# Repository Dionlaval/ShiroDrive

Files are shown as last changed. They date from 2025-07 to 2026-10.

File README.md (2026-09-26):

# ShiroDrive

ShiroDrive is an independent motion-control project focused on modular motor-drive hardware and experimental robotic systems.

The current hardware direction includes both stepper control and compact, networked FOC servo modules.

This is an evolving engineering project.

---

## Core Direction

ShiroDrive currently explores:

- Custom stepper motor driver design
- Dynamic microstepping techniques
- Smooth motion across wide velocity ranges
- Resonance mitigation and control refinement
- CoreXY motion architectures

The stepper platform uses ESP32, while ShiroFOC is based on the STSPIN32G4 with its embedded STM32G431 motor-control MCU.

ESP32 provides:

- Real-time capable control
- Flexible peripheral configuration
- Wireless debugging and telemetry
- Rapid prototyping flexibility

STSPIN32G4 provides:

- Integrated STM32G4 real-time motor-control MCU
- Three external-MOSFET gate drivers
- Integrated current-sense op-amps and hardware protection comparators
- CAN-based modular communication
- Compact single-axis FOC architecture

---

## Building Block

### ShiroDrive Step

A custom stepper motor control platform.

Focus areas:

- Dynamic microstepping
- High-speed stability
- Clean current control
- Modular PCB design
- Firmware-driven motion refinement

This board forms the foundation of all current machines.

### ShiroFOC

A single-axis, 48 V-class FOC servo module for robotics.

Planned features include:

- STSPIN32G4 controller and external three-phase MOSFET bridge
- Three-shunt phase-current sensing
- CAN communication to a coordinating motherboard
- Integrated magnetic encoder and 6-axis IMU
- External Hall and encoder inputs
- SWD programming and debug

See [ShiroFOC design constraints](ShiroFOC/docs/DESIGN_CONSTRAINTS.md) for the preliminary Rev A targets.

---

## Experimental Machine

### Manga Draw

A CoreXY-based pen plotting platform.

Purpose:

- Investigate high-speed planar motion
- Develop scalable XY architecture
- Render anime-style posters and manga panels with precision
- Serve as a validation platform for ShiroDrive Step

The architecture is designed to scale beyond desktop format.

---

## Development Status

### Currently Working On

- ShiroDrive Step PCB iteration
- Motion firmware development (ESP32)
- CoreXY Manga Draw platform integration

### Next Steps

- Refinement of dynamic microstepping
- Mechanical rigidity improvements
- Higher current driver revisions
- Closed-loop motion experimentation

---

ShiroDrive documents the process of building motion systems from first principles — hardware, firmware, and mechanical integration.

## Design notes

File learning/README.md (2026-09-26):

# ShiroFOC weekend learning lab

**Start with [the interactive lab](index.html)**. Open `index.html` in a browser; it works offline, with no installation or server. Work through one chapter at a time alongside [the notebook](docs/NOTEBOOK.md).

This package turns the [learning plan](docs/PCB_DESIGN_LEARNING_PLAN.md) into worked models, experiments and board-specific explanations. It is designed for a mechanical engineer with a robotics and control background.

## Suggested route

| Session | Read and do | Approximate time |
|---|---|---|
| Saturday morning | Notebook §§1–3; lab “Switching”; exercises 1–3 | 1.5–2 h |
| Saturday afternoon | Notebook §§4–7; “Capacitors” and “Supply & energy”; exercises 4–8 | 2–3 h |
| Sunday morning | Notebook §§8–10; “Placement” and “Sensing”; exercises 9–12 | 2–3 h |
| Sunday afternoon | Notebook §11; decision record; write your own capacitor decision | 1–2 h |

Take breaks between models. You do not need to absorb all the equations before experimenting.

## Deliverables

- [Interactive lab](index.html): live switching, capacitor, RLC, gate-drive and sensing models. Hover/touch plots to inspect values; controls show units.
- [Guided notebook](docs/NOTEBOOK.md): physical explanations, worked numbers and predictions.
- [Board inputs](docs/BOARD_INPUTS.md): actual component values, operating targets and assumed parameters.
- [Model guide](docs/MODEL_GUIDE.md): derivations, topology definitions, implementation details and limits.
- [Exercises with answers](docs/EXERCISES.md): prediction-first experiments and numerical checks.
- [Decision record](docs/DECISION_RECORD.md): consequences for this board and what remains undecided.
- [Sources](docs/SOURCES.md): project evidence and primary engineering references.
- [Figures](figures/): standalone PNG and SVG plots, power-path diagram and actual placement overview.
- [Comparison CSV](data/comparison.csv), [JSON](data/comparison.json) and waveform CSVs: reusable numeric results.
- [Python model](models/build_models.py) and [browser model](models/lab_models.js): editable, documented implementations.
- [Runnable Jupyter notebook](ShiroFOC_learning.ipynb): optional computational companion; the browser lab requires no Python.
- [Validation notes](qa/VALIDATION.md): checks, coverage and known limitations.

## What is real, and what is an example?

The hardware snapshot is the **P1 schematic and P0 unrouted component placement**, as read on 19 September 2026. Component values come from the project. Motor parameters, cable impedance, capacitor parasitics and ceramic DC-bias retention are explicitly assumed. The ceramic candidates are study cases, not selected parts or released hardware changes.

The current schematic still has three 680 µF electrolytics. No schematic or PCB was changed by this learning package. Parts availability and fabricator validation were not performed, as requested earlier.

## Reproduce the calculations

With Python 3.10+ and the dependencies in [requirements.txt](models/requirements.txt):

```sh
python -m pip install -r learning/models/requirements.txt
python learning/models/build_models.py
python learning/models/build_package.py
python learning/models/validate_reference.py
node learning/models/check_models.cjs
node learning/models/check_lab_wiring.cjs
```

Run these commands from the repository root. The first Python script also works from another directory. The scripts write only learning artifacts, not hardware design files. The package includes the schematic analysis snapshot; regenerating that snapshot requires the KiCad skill's analyzer or an equivalent extraction.

The calculations use linear circuit models and ideal switches. They are useful for understanding and comparing choices; they do not constitute measured board performance, an EMC review, or a fabrication release.

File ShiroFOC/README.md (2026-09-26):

# ShiroFOC workspace

## Start here

- **[Manual rebuild](Manual_Rebuild/ShiroFOC_Manual.kicad_pro)** — complete reference schematic with your manual MOSFET bridge retained, ready for page-by-page review; [library instructions](Manual_Rebuild/README.md).
- [P1 reference project](ShiroFOC_KiCad_P1/ShiroFOC_KiCad.kicad_pro) — existing schematic and revised component placement.
- [Saved routing review](routing_review_2026-09-21/README.md) — independent snapshots of the incomplete routing, paused for review.
- [Learning lab](../learning/README.md) — interactive models, exercises and explanations.

The original design files remain in their project folders. Routing is incomplete; the saved boards are not fabrication releases. The notes below document different design stages.

## Design notes

### Schematic and firmware

- **[Current firmware requirements](requirements/FIRMWARE_REQUIREMENTS.md)** — manual rebuild: safe startup, persistent BOOT0, calibration storage, sensors, current protection and brake control.

- [Design constraints](docs/DESIGN_CONSTRAINTS.md)
- [Rev A schematic plan](docs/SCHEMATIC_REV_A_PLAN.md)
- [Rev A design review](docs/DESIGN_REVIEW_REV_A.md)
- [Schematic readability plan](docs/SCHEMATIC_READABILITY_PLAN.md)
- [Schematic redraw review](docs/SCHEMATIC_REDRAW_REVIEW.md)
- [MCU pinout and interfaces](docs/MCU_PINOUT_AND_INTERFACE_PLAN.md)
- [Historical A0 firmware bring-up contract](docs/FIRMWARE_BRINGUP_CONTRACT.md)

### PCB

- [Layout guidelines and DRC settings](docs/PCB_LAYOUT_GUIDELINES.md)
- [Layout handoff](docs/PCB_LAYOUT_HANDOFF.md)
- [Original placement notes](docs/PCB_PLACEMENT_P0.md)
- [Revised placement notes](docs/PCB_PLACEMENT_P1.md)
- [P1 revision list](docs/PCB_REVISION_LIST_P1.md)
- [Capacitor options study](docs/PCB_CAPACITOR_OPTIONS_2026-09-17.md)

## Folder guide

| Folder | Contents |
|---|---|
| `Manual_Rebuild/` | Your schematic review copy, imported CAD and download checklist |
| `requirements/` | Current implementation requirements for the manual rebuild |
| `docs/` | Design plans, decisions and review notes |
| `ShiroFOC_KiCad/` | Original reference project and its outputs |
| `ShiroFOC_KiCad_P1/` | Revised placement project and routing experiments |
| `routing_review_2026-09-21/` | Saved routing checkpoints for inspection |
| `tools/` | Existing generation, checking and routing scripts |
| `backups/` | Preserved files, including the notes before this cleanup |

The documentation cleanup moved notes and repaired links; it did not change the existing circuitry or routing.

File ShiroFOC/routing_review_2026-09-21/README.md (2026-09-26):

# Routing review checkpoint — 21 September 2026

**Paused for the user's visual review. Nothing here is a finished PCB.** Original P0, P1 placement and all routing candidates are preserved. No more routing changes should be made until the user provides their hint or asks to resume.

## Which board to open

| Project folder | Purpose | Unconnected items | Other error-severity DRC violations |
|---|---|---:|---:|
| `latest_trial` | Latest placement/corridor experiment; open this first | 152 | 0 |
| `best_baseline` | Most complete checked connectivity before the corridor reset | 91 | 0 |
| `gate_loop_comparison` | Seven gate/reference connections, but some outgoing/return routes form large loops; comparison only | 149 | 0 |

Open `ShiroFOC_KiCad.kicad_pro` or `.kicad_pcb` in each folder. Each includes the schematic hierarchy, local libraries, board rules and native DRC checkpoint. Counts refer to KiCad's unconnected **items**, not distinct nets. Zero other errors does not mean clean DRC: all boards remain incomplete and have warnings.

## Most useful area to examine

The corridor from U301's upper/right gate-driver pins to Q401/Q402/Q403 and their gate resistors. In native KiCad coordinates this is approximately **X 137–170 mm, Y 128–164 mm** (board-local X 37–70, Y 28–64).

- Highlight **GHS1 + OUT1**, **GHS2 + OUT2**, and **GHS3 + OUT3** in turn. Each high-side gate signal needs its matching phase-reference return close by.
- Check the remaining **GLS1/2/3** routes alongside their source/ground return environment.
- The six **SHUNT_*_SENSE_P/N** traces and underside ratio networks are already connected; preserve their Kelvin pickoff and avoid routing gate signals alongside them for long distances.
- Examine C412/C422/C432 and the adjacent source/shunt via banks on both faces. A passage that appears open on top may be blocked underneath.
- Preserve the wide **VM** feed and the **FORCE_P** / shunt / GND current paths. A route that cuts their only useful copper bridge is not an acceptable improvement.

A useful hint would be a preferred routing corridor, a different ordering of these paths, or a suggested relocation of the MCU-side parts / phase-cell passives. No need to solve all remaining ordinary signals.

## What the latest trial contains

- Ordinary unlocked routes around the driver corridor were removed deliberately. This explains the higher unconnected count than the baseline.
- R301 and C306 moved to open an underside corridor; R602 retained at the earlier clean location. GHS1/GHS3 outward fanouts and additional driver fanouts remain.
- C412/C422/C432 were rotated horizontally; their VM/GND via arrangements changed. Six gate resistors moved 0.2 mm sideways to maintain component courtyards.
- Local 0.20 mm clearance regions were added around those populated capacitor/gate-resistor areas. Existing global and MCU/package rules remain.
- The middle-phase reference route was previously trapped. It now has a roughly 23.5 mm new connecting path. All three OUT reference connections are present in this latest trial, but their matching gate routes still need to be established as close pairs.
- Remaining warnings include narrow copper connections around the revised via arrays, dangling items and inherited silk/library warnings. These have **not** been accepted as final.

## Why routing is paused

Repeated shortest-path routing was reducing connectivity counts without preserving gate-return geometry. Some routes were rejected for 90–154 mm detours; others connected successfully but created large loops or isolated power copper. The experiments found specific placement bottlenecks, but a visual hint is now more efficient than another automatic iteration.

## Still outstanding after the hint

Finish paired gate routing and ordinary signals; restore/check bus copper continuity and ground stitching; recheck native DRC and schematic/PCB parity; perform the critical return-path/EMI/thermal review; implement low-tradeoff high-priority fixes; produce the requested actual-PCB wireframe and colour-coded routing presentation. External fabricator and component-availability checks remain excluded as requested.

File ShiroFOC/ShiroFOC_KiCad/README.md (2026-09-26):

# ShiroFOC A1-Drawing - schematic ready for prototype PCB layout

**P1 revision notes:** see [../PCB_REVISION_LIST_P1.md](../docs/PCB_REVISION_LIST_P1.md). H1-H4 are now in the schematic; the P0 PCB still awaits the mounting holes and placement revision. Earlier parity reports and release PDFs/ZIPs predate this change.

**PCB P0 placement is now available:** all 260 footprints on an 80 × 80 mm rounded-square, four-layer board. See [placement notes and previews](../docs/PCB_PLACEMENT_P0.md). Open the existing `.kicad_pcb`; it remains unrouted. The prior schematic release archives and manifests describe the earlier release, not this placement checkpoint.

Open `ShiroFOC_KiCad.kicad_pro` in **KiCad 9**. The project contains 12 native schematic sheets with connected functional blocks and project-local symbols/critical footprints. Standard footprints resolve through KiCad 9's installed libraries. A1-Drawing preserves all A0 electrical connections, components, values, MPNs, footprints and DNP choices.

Start with [design review](../docs/DESIGN_REVIEW_REV_A.md), [PCB layout handoff](../docs/PCB_LAYOUT_HANDOFF.md), and [firmware contract](../docs/FIRMWARE_BRINGUP_CONTRACT.md). No PCB has been routed. Current/voltage goals still require hardware qualification; the review identifies ripple, thermal, USB-power and braking limits.

## Release contents

- `libs/ShiroFOC_Redraw.kicad_sym`: functional symbols, including multi-unit STSPIN and analog switches, with complete physical pin mapping.
- `libs/ShiroFOC.pretty`: four datasheet-derived footprint types.
- `outputs/ShiroFOC_Rev_A_Schematic.pdf`: reviewed, searchable 12-page schematic (ten A3 and two A4 pages).
- `outputs/ShiroFOC_Rev_A_BOM.csv`: one row per reference, including DNP and procurement specifications.
- `outputs/ShiroFOC_Rev_A.net`: KiCad XML netlist.
- `outputs/erc_rev_a.json`, `validation_report.json`, `footprint_audit.json`, `footprint_pad_audit.csv`: release verification evidence.
- `outputs/electrical_calculations.json`: current-sense, brake-threshold, bus and rail calculations.
- `outputs/visual_review.json`, `release_manifest.json`: reviewed PDF/pages and SHA-256 release hashes.
- `outputs/net_name_aliases.json`: maps KiCad's local/hierarchical net names to the A0 names used by the handoff. Complete physical pin groups are verified independently of naming.
- `../review_baselines/A0_before_redraw/`: frozen connectivity and BOM used by the validator.

## Rebuild

Requires Python 3.12+ and KiCad 9 CLI, plus a Python interpreter containing `pcbnew`. From the ShiroFOC directory:

```sh
python3 tools/release_rev_a.py
```

On macOS the script discovers the standard `/Applications/KiCad/` installation. Other installations can set `KICAD_CLI`, `KICAD_PYTHON`, and `KICAD9_FOOTPRINT_DIR`. `KICAD_PYTHON` must import pcbnew. Set `FONTCONFIG_FILE` to a valid local fontconfig configuration if that installation needs one for headless PDF export.

`generate_rev_a.py` retains the electrical definitions. `native_rev_a.py` now delegates to `redraw_rev_a.py`; `redraw_core.py`, `redraw_power.py`, `redraw_analog.py` and `redraw_interfaces.py` define the connected drawings using `redraw_engine.py`. No legacy GUI conversion is needed. UUIDs are stable between redraw builds. **Rebuild overwrites generated native sheets and the redraw symbol library.** If editing in KiCad, also reconcile those changes into the layout modules before rebuilding. The checked-in custom footprints, project settings and handoff documents are preserved.

The overview contains navigable child sheets and graphic system connections. Circuit boundaries use named global ports; local circuits use wires and junctions. STSPIN units A/B/C/D/E/F remain one physical U301. See [redraw review](../docs/SCHEMATIC_REDRAW_REVIEW.md) for the sheet map and validation scope.

Rebuild regenerates machine checks but does not perform visual approval. Render and inspect the new PDF; refresh `visual_review.json` with its exact hash only after review, then run `python3 tools/release_rev_a.py --manifest-only`. That final command checks the visual hash and writes the release manifest. Keep review status separate from a successful CLI export.

## Start PCB layout

Continue from the existing P0 PCB. Use Update PCB from Schematic when synchronizing subsequent schematic changes. Keep all DNP footprints on-board; fitted state is controlled by the native DNP property and Assembly field. Follow the handoff for Kelvin routing, DC-link return points, live VIN thermal pads, optional termination and external connector restrictions. Preserve U901's documented thermal-drill adjustment when updating footprints. Resolve mechanical fit, copper/current sizing, DRC and fabrication details during PCB work.

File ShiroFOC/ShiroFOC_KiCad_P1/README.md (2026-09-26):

# ShiroFOC P1 layout

Open `ShiroFOC_KiCad.kicad_pro` in this directory. This is the revised **unrouted component placement** with parallel phase columns, four M3 holes and all three original bulk electrolytics.

See [placement notes and validation](../docs/PCB_PLACEMENT_P1.md). The original project is preserved in `../ShiroFOC_KiCad`; its saved project and libraries are also in [the P0 backup ZIP](../backups/ShiroFOC_P0_before_parallel_bridges_2026-09-19.zip).

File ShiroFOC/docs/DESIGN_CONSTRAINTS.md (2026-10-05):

# ShiroFOC Rev A Design Constraints

Status: A0 architecture baseline, reconciled with the layout release. Current and power ratings remain prototype goals until verified by thermal and fault testing. [DESIGN_REVIEW_REV_A.md](DESIGN_REVIEW_REV_A.md) records final values, calculation results, deviations and operating limits.

The proposed GPIO allocation and interface details are maintained separately in [MCU_PINOUT_AND_INTERFACE_PLAN.md](MCU_PINOUT_AND_INTERFACE_PLAN.md).

## Product intent

ShiroFOC is a compact, single-axis FOC motor-drive module for consumer and research robotics, including small robotic arms, quadrupeds, balancing platforms, mobile robots, and compact servo actuators.

Each module closes its own current, velocity, and position loops. A motherboard coordinates multiple modules over CAN.

## Fixed architecture

- One STSPIN32G4 only; use its embedded STM32G431 MCU, three gate drivers, op-amps, comparators, and internal VM-to-VCC buck regulator. Bypass its internal 3.3 V regulator and supply the MCU/logic from the external 3.3 V rail.
- One external N-channel MOSFET three-phase bridge (six MOSFET positions minimum).
- Three low-side shunts with Kelvin sensing for phase-current reconstruction and true three-shunt FOC.
- Hardware overcurrent shutdown independent of firmware, using the integrated comparator/break path.
- CAN bus is the primary command, configuration, telemetry, and update transport.
- Integrated 6-axis BMI323 IMU over 4-wire SPI.
- Integrated on-axis magnetic encoder over SPI, subject to mechanical alignment with the shaft magnet.
- External feedback connector supporting Hall U/V/W and at least one configurable encoder interface.
- Three power-stage NTCs, one per half-bridge.
- DC-bus voltage monitoring.
- Temperature telemetry and overtemperature warnings over CAN for system-level cooling control.
- USB-C service interface through a USB-to-UART bridge.
- Mandatory SWD programming/debug connector.
- No second application MCU.

## Electrical rating target

### Battery and DC bus

- Battery range: 6S to 10S LiPo/Li-ion.
- Recommended design point: 8S, 29.6 V nominal and 33.6 V fully charged.
- Maximum supported pack: 10S, 37.0 V nominal and 42.0 V fully charged.
- Normal DC-bus operating target: approximately 18 V to 42.0 V.
- Rev A power stage: three TI CSD88599Q5DC 60 V DualCool half-bridge power blocks, one package per phase. Parallel packages are deferred to a possible Pro version.
- The design must control regenerative rise and switching overshoot with meaningful margin below the MOSFETs' 60 V absolute maximum; 10S support depends on measured switching behavior and a validated clamp/brake strategy.
- DC-link capacitors: 63 V minimum. Their ripple-current, temperature, lifetime, and transient margin must be validated; a 63 V capacitor rating does not justify allowing the bus to approach 60 V.
- Include local ceramic DC-link capacitance immediately adjacent to each half-bridge and bulk capacitance at the power entry.
- Rev A omits onboard reverse-polarity protection. Use a keyed/polarized battery connection and clearly mark polarity; reverse battery connection is an unsupported fault condition.
- Include bus-voltage measurement and reserve an optional input TVS/clamp footprint. Any populated clamp must be coordinated with the brake-chopper threshold and the 42 V maximum charged pack voltage.
- Keep the VM path bidirectional so intentional regenerative current can return to a battery.
- Provide a local brake-chopper switch and external brake-resistor connector on every ShiroFOC so one module can operate safely without a motherboard. In a multi-axis system a central chopper may be the primary dump, while local choppers use a slightly higher threshold as independent backup protection.
- A battery may absorb regeneration only if its BMS, charge state, temperature, and wiring permit it. A bench or industrial PSU must be assumed unable to sink energy unless explicitly specified otherwise.

### Auxiliary power architecture

- Generate `5V_BAT` directly from VM with an external wide-input switching regulator rated for the complete 10S bus and its permitted transients. Current Rev A choice: LMR36510F, 5 V / 1 A, forced-PWM variant.
- Accept USB-C VBUS as `5V_USB`. Battery and USB-C may be connected simultaneously.
- Feed `5V_BAT` and `5V_USB` into a reverse-current-blocking power mux. USB-C is the preferred source whenever valid; otherwise select `5V_BAT`. The sources must never be tied directly together.
- Name the mux output `5V_SYS`. It powers the external 3.3 V LDO. CP2102N `VREGIN` and `VDD` both use `3V3` in regulator-bypass mode. The bridge's USB-presence `VBUS` pin senses raw USB VBUS through the manufacturer-recommended divider.
- Generate `3V3` from `5V_SYS` with the external TLV75533P LDO. This rail powers the embedded MCU, IMU, selected encoder/Hall interface, feedback mux, CAN transceiver, and other low-voltage logic.
- Configure the STSPIN32G4 for externally supplied 3.3 V according to its regulator-bypass requirements; do not connect two active 3.3 V regulator outputs together.
- Independently use the STSPIN32G4 internal buck from VM to generate gate-driver `VCC`. The supported setting is 8 V to 15 V; use 10 V as the Rev A starting point and validate gate loss, MOSFET enhancement, bootstrap behavior, and STSPIN temperature before changing it.
- USB-only operation powers control, communications, and sensors but not VM, VCC, the inverter, or the brake-chopper gate driver. Firmware must detect that VM is absent and inhibit all power-stage commands.
- Budget `5V_SYS` and `3V3` for worst-case simultaneous loads, including dominant CAN transmission, the onboard AS5047P, and the maximum permitted external feedback load. The feedback mux does not switch sensor power.
- If VM returns while USB has kept `5V_SYS` and the MCU alive, firmware must perform a full power-stage reinitialization before enabling inverter or brake PWM.

### Local brake chopper

- Implement the Rev A brake chopper as a low-side N-channel MOSFET switch: raw `VM` to the external brake resistor, resistor return to `BRK_SW`, brake MOSFET drain to `BRK_SW`, and brake MOSFET source to PGND.
- Provide a clearly keyed two-pin external resistor connector carrying raw `VM` and `BRK_SW`. Both pins can be hazardous at the full DC-bus voltage; do not use a connector that can be confused with a low-voltage sensor interface.
- Drive the brake MOSFET through a dedicated low-side gate-driver IC powered from 10 V VCC. Do not drive the power MOSFET gate directly from a 3.3 V MCU pin.
- Use PB9 `BRAKE_PWM` / TIM17_CH1 as the control output. Add a physical pull-down at the gate-driver input and a gate-source pull-down so the software command defaults off. The fitted hardware OV comparator can command braking during reset when VM exceeds its threshold and both 3V3/VCC are present. USB-only or an unpowered gate driver cannot switch the chopper.
- Select the brake MOSFET with more voltage margin than the 60 V phase power blocks; start the search at 80 V. Validate repetitive pulse SOA, avalanche behavior, switching loss, package thermal impedance, and resistor-current fault behavior rather than selecting only from low RDS(on).
- Size the external resistor from both instantaneous power and braking energy. At a given bus voltage, chopper current is approximately `VBUS / RBRK` and instantaneous resistor power is approximately `VBUS^2 / RBRK`. Motor/load energy that must be removed is approximately `0.5 * J * (omega_start^2 - omega_end^2)`.
- Firmware must use bus-voltage hysteresis and PWM duty control rather than uncontrolled rapid on/off chatter. Thresholds must remain configurable for the installed battery/PSU and resistor.
- Set the normal local-chopper threshold above the maximum expected charged-battery voltage but comfortably below the voltage allowed by the MOSFETs, capacitors, regulator inputs, and ADC protection. A 10S system cannot wait until close to 60 V before beginning to dump energy.
- Reserve a footprint or control path for a hardware overvoltage backup that can command the brake driver independently of normal firmware. This is backup protection, not a substitute for correct firmware, a TVS, or adequate DC-link capacitance.
- A TVS handles short spikes; the brake resistor handles sustained regenerative energy. Do not size either component as though it performs both jobs.

### Power entry, long cables, and inrush

- Expect the DC cable inductance and local low-ESR input capacitance to form an LC resonant circuit. Hot-plugging, abrupt current changes, a released short, or regenerative current can excite it and produce a local VM peak much higher than the battery/PSU voltage.
- Rev A does not include an onboard active precharge/inrush MOSFET. Characterize connector arcing and capacitor-charging current with the final populated DC-link bank (P3: 48 × 10 uF / 100 V ceramics; substantial DC-bias derating); add a system-level anti-spark/precharge solution where the application requires frequent hot-plugging.
- Provide footprints near the power connector for an input damping branch consisting of a series R-C network across VM and PGND. Final values depend on cable inductance, installed bus capacitance, and measured hot-plug response; do not populate arbitrary values before characterization.
- Include some intentional damping through a suitable bulk capacitor/ESR strategy. Do not add a series input inductor or ferrite merely to reduce noise: without damping it can worsen the resonance.
- A TVS is a short-transient clamp, not an inrush limiter or regenerative-energy dump. Select its working and clamping voltages against the 42 V maximum pack, 60 V MOSFET limit, pulse current, and temperature.
- Validate the driver at the maximum intended cable length and wire gauge, including hot-plug, motor braking, supply disconnection, and BMS opening events.

### DC-bus monitoring

- Measure motor VBUS with a dedicated STM32 ADC input.
- Size the resistor divider so the ADC remains below its absolute maximum at the highest possible clamped fault voltage, not merely at the 42.0 V maximum charged-pack voltage.
- Use sufficiently voltage-rated series resistors in the upper divider leg; split the resistance across multiple packages when required for voltage rating, creepage, and fault tolerance.
- Add a local RC anti-alias/noise filter at the ADC input.
- Add an ADC-input protection/clamp strategy that cannot back-power `3V3` during an unpowered or fault condition.
- Use tolerance appropriate to bus protection and calibrate divider gain in production firmware if accurate power telemetry is required.
- Firmware must implement configurable undervoltage, overvoltage, and regenerative-overvoltage thresholds.
- Hardware transient protection must remain effective without firmware; ADC monitoring is not a substitute for the bus clamp or correctly rated components.

### Current and power goals

- Passive/free-air continuous phase current goal: 25 Arms.
- Continuous phase current goal with a defined heatsink or forced airflow: 40 Arms.
- Short peak phase current goal: 80 A peak for no more than 2 seconds, subject to junction-temperature and shunt limits.
- Initial hardware overcurrent trip target: below 90 A peak, finalized from MOSFET SOA, shunt range, amplifier saturation, and comparator tolerance.
- Current ratings refer to motor phase current, not battery current.
- Honest initial product class: approximately 1 kW continuous without aggressive cooling, approximately 1.5–2 kW with a validated thermal solution, and higher short-duration peak power. Exact mechanical output depends on motor speed, winding, modulation, and efficiency.
- Do not publish a continuous power rating until tested at maximum ambient temperature in the intended enclosure.

The STSPIN32G4 architecture is not intrinsically limited to 40 A because it drives external MOSFETs. ST demonstrates the same architecture at up to 3 kW and 63 Arms with additional cooling. The limiting factors are the MOSFETs, switching losses, copper, connectors, shunts, capacitors, thermal path, and transient protection.

## Power-stage constraints

- Select MOSFETs using total loss, not RDS(on) alone: conduction loss, gate charge, switching loss, reverse recovery, output capacitance, and thermal resistance all matter.
- Size the STSPIN gate-drive voltage and gate resistors from the selected MOSFET, target PWM frequency, EMI, and switching-loss measurements.
- Default PWM-frequency design point: 20 kHz. Keep 30 kHz feasible if losses and thermals permit.
- A0 fits one series resistor per gate and reserves phase RC snubbers. Diode-assisted independent turn-on/turn-off paths are deferred; tune the fitted resistors from measurements.
- Provide gate-source pull-down resistors and tight gate-drive loops.
- Place ceramic bus capacitors directly across the high-current bridge supply loop.
- Keep switch nodes compact and away from current-sense, encoder, IMU, CAN, and SWD circuitry.
- Reserve a series R-C snubber footprint from each phase switch node to the appropriate local power return, placed immediately beside its CSD88599Q5DC. Start DNP and tune from measured ringing; do not copy values from another PCB.
- Gate-resistor tuning and phase-node R-C snubbing are complementary: slower gate edges reduce excitation, while a correctly tuned snubber dissipates energy in the parasitic LC resonance. Both trade reduced ringing/EMI against additional switching loss.
- Provide real heatsink attachment or a defined chassis conduction path; copper area alone is not assumed sufficient at 40 Arms.

## Current sensing

- Use three four-terminal/Kelvin shunts where sourcing permits.
- Preliminary shunt range: 0.5 to 1.0 milliohm. Final value follows ADC range, op-amp gain, minimum measurable current, power dissipation, and overcurrent threshold analysis.
- Route each differential sense pair directly from the shunt sense terminals to the assigned integrated op-amp inputs.
- Never share sense traces with force-current copper or general ground-return paths.
- Match input filtering and gain networks across all three channels.
- Sample synchronously with center-aligned PWM.
- Use the integrated comparator and timer break input for cycle-independent hardware shutdown.

## Thermal monitoring and cooling

### Power-stage temperature sensing

- Fit three NTC thermistors, one per half-bridge. One sensor for the entire bridge is not sufficient for the 40 Arms design target because phase loading, airflow, solder quality, gate faults, and heatsink contact can produce asymmetric temperatures.
- Place each NTC as close as practical to the thermally representative MOSFET copper for its phase, preferably between or immediately beside the high-side and low-side devices without enlarging the switching loop.
- Do not place an NTC directly on a switch-node copper island if its divider would create an unsafe high-dV/dt coupling path. Maintain electrical isolation while maximizing thermal coupling.
- Connect each NTC divider to a separate ADC channel where pin allocation permits.
- Use identical NTCs and divider networks across all phases.
- Preliminary choice: 10 kohm NTC at 25 degrees C, 1% B-value tolerance where available, with the fixed divider resistor selected to maximize useful resolution in the expected 40 to 120 degrees C range.
- Firmware must use the hottest of the three readings for CAN thermal telemetry, current derating, and shutdown.
- Preliminary policy targets: issue an early thermal warning near 50 degrees C, begin current derating near 90 degrees C, and shut down near 110 degrees C. Final thresholds must be derived from the selected MOSFET, PCB-to-sensor thermal lag, capacitor ratings, connector ratings, and heatsink tests.
- Detect open-circuit and short-circuit NTC faults and fail to a conservative current limit.

### MCU and STSPIN temperature

- Do not add a separate external NTC for the MCU in Rev A.
- Use the STM32 internal temperature sensor for telemetry and software derating, and rely on the STSPIN32G4's internal thermal shutdown as the final device-level protection.
- Keep the option to add a board-temperature test footprint near the STSPIN32G4 if prototype measurements show that its local temperature is not represented adequately by the internal sensor.

### System-level cooling

- Rev A does not generate fan power and does not include a fan connector, fan PWM output, or tachometer input.
- Size and rate the motor-driver module for a defined passive heatsink or chassis-conduction path without relying on a fan.
- Broadcast all three power-stage temperatures, the hottest temperature, thermal-warning state, and derating state over CAN.
- A motherboard may control enclosure or system fans from this telemetry, but local current derating and shutdown must remain autonomous and must not depend on CAN or a motherboard response.

## Communications

### CAN

- CAN is mandatory and is the normal external interface.
- Use the STM32G431 FDCAN peripheral with a 3.3 V CAN transceiver rated for the selected bus speed.
- Initial interoperability target: Classical CAN at 1 Mbit/s. Preserve CAN-FD capability in the hardware.
- Connector signals: CANH, CANL, signal ground, and shield/chassis provision where applicable.
- Fit ESD protection close to the connector.
- Rev A uses fitted 0 ohm CANH/CANL links. A true common-mode choke is deferred unless EMC testing shows it is required.
- Provide selectable 120 ohm termination; default DNP because only the two physical bus ends are terminated.
- Provide unique node identification by firmware-configurable ID, resistor straps, or a commissioning protocol.
- Configuration and telemetry must work over CAN. Plan for a CAN firmware-update bootloader after initial SWD bring-up.

### USB/UART

- Fit a USB-C-to-UART service interface on Rev A for direct PC control, commissioning, logs, diagnostics, and interactive commands.
- USB-UART is a local service interface; CAN remains the normal production command, configuration, telemetry, and firmware-update transport.
- A USB-UART bridge can also provide STM32 ROM-UART programming when a supported UART pin pair, BOOT0 entry, and reset control are correctly implemented.
- USB-UART does not replace SWD for recovery and real debugging.
- Prefer a bridge with a separate VIO supply or verified 3.3 V UART levels.
- USB VBUS may power the complete `5V_SYS`/`3V3` control domain through the power mux. It must never energize VM, the STSPIN VCC gate-driver rail, the inverter, or the brake chopper.
- Prevent UART, reset, and boot-control signals from back-powering an unpowered STSPIN32G4 through its GPIO protection diodes. Use appropriate series resistance, isolation, or a bridge power arrangement validated for both power-up orders.
- Include USB-C USB 2.0 sink configuration with the required CC1 and CC2 pull-down resistors, connector-adjacent low-capacitance ESD protection, and controlled D+/D- routing.
- Connect the USB shield using a deliberate chassis/EMI strategy rather than automatically shorting it into a noisy power return at the connector.
- Reserve series-resistor footprints on UART TX and RX for signal integrity and isolation during bring-up.
- Provide manual BOOT0 and NRST access. Automatic bootloader entry using bridge handshake outputs is optional and must not interfere with normal operation.
- Expose UART TX/RX/GND test pads even though USB-UART is fitted.
- Firmware must offer the same core configuration object model over USB-UART and CAN so the two interfaces do not become separate maintenance paths.

## Programming and debug

- Use the 10-pin 1.27 mm Arm Cortex debug connector wired for SWD; a full JTAG interface is not required.
- Required signals: VTREF/3V3, SWDIO, SWCLK, NRST, and GND.
- SWO is not routed in Rev A because PB3 is committed to SPI3_SCK. SWDIO, SWCLK, NRST, VTREF, and GND provide the required debug path.
- Keep SWD traces short and accessible with the power stage assembled.
- SWD is the guaranteed first-programming, recovery, option-byte, and fault-debug path.
- Keep BOOT0 and NRST accessible by pads regardless of the USB-UART circuit state.

## Sensors and feedback

### Integrated magnetic encoder

- Use 4-wire SPI with a dedicated chip-select pull-up.
- The encoder must be mechanically centered on the motor axis within its datasheet tolerance.
- Keep motor phase copper and high-current vias away from the encoder and magnet region.
- If the PCB cannot physically occupy the shaft axis, move the encoder to a small daughterboard rather than compromising alignment.

### BMI323 IMU

- Use 4-wire SPI and connect INT1 to an interrupt-capable MCU GPIO.
- INT2 is optional but should be routed if pin budget allows.
- Power VDD and VDDIO from filtered `3V3` with the mandatory local decoupling.
- Locate the IMU away from MOSFETs, inductors, mounting-hole stress, board edges, and strong thermal gradients.
- Mark the IMU X/Y/Z orientation on silkscreen and in firmware documentation.
- The IMU is for body motion, tilt, impact, and vibration. It is not a substitute for shaft feedback.

### External feedback

- Support Hall U/V/W with configurable pull-ups and input filtering.
- Support incremental A/B/Z inputs at 3.3 V logic.
- External digital feedback in Rev A is ABI/index or Hall U/V/W only. External SPI/SSI feedback is deferred to a later revision.
- External-feedback inputs require ESD protection and series/filter footprints appropriate to cable length.
- Do not expose unprotected STM32 pins directly on a motor cable connector.

## PCB and mechanical constraints

- P3 uses six copper layers; see [ceramic / six-layer revision](PCB_CERAMIC_SIX_LAYER_2026-10-04.md).
- Approved P3 copper: 2 oz top/bottom, 0.5 oz on all four inner layers. L2/L5 GND, L3 signals, L4 power. The nominal dielectric geometry needs a matching fabrication build before impedance signoff.
- Separate power-stage, control/sensing, and connector zones while maintaining deliberate return-current paths.
- No high-current path through thermal-relief spokes.
- Use planes, pours, via arrays, and exposed copper/heatsink interfaces sized from current-density and thermal calculations.
- Minimize the commutation loop: bulk/ceramic capacitor to high-side MOSFET to low-side MOSFET/shunt and back to capacitor.
- Keep CAN and sensor routing out of switching-node regions.
- Target envelope: approximately 50 mm x 80 mm before connector/heatsink optimization, comparable to ST's compact high-power reference-design class.
- Define airflow, heatsink, mounting pressure, insulation, and maximum enclosure ambient as part of the electrical rating.

## Protection and validation gates

- Input surge, ESD, shoot-through, phase short, motor-stall, shunt-open, encoder loss, CAN fault, overtemperature, and regenerative overvoltage must have defined behavior. Reverse battery connection is explicitly outside the Rev A protection envelope.
- Measure MOSFET VDS overshoot with a suitable differential probe at maximum bus voltage and current.
- Validate hardware overcurrent shutdown before closed-loop high-power testing.
- Instrument MOSFET, shunt, capacitor, connector, STSPIN32G4, and PCB temperatures.
- Correlate all three NTC readings with measured MOSFET junction/case temperatures during characterization, including single-phase asymmetric loading and blocked-airflow tests.
- Validate current-sense offset/gain over temperature and under PWM common-mode disturbance.
- Ratings require testing at minimum and maximum battery voltage, intended PWM frequency, maximum ambient, stalled/low-speed operation, and regenerative braking.
- Rev A bring-up begins with a current-limited bench supply and low voltage; LiPo testing comes only after protection functions are proven.

## Prototype validation items

The Rev A schematic fixes the electrical architecture and the first-build component choices. The following items are intentionally completed during PCB layout, bring-up, or characterization rather than left as missing schematic circuits:

- Verify the CSD88599Q5DC, CSD19531Q5A, and TLV75533P custom land patterns against printed 1:1 package drawings and the chosen fabricator's via-in-pad process.
- Confirm the 0.5 milliohm shunts, gain of 28 with midscale bias, VDS/SCREF threshold, ADC range, and comparator hardware overcurrent threshold together before high-current testing.
- Validate the VBUS divider and ADC protection strategy against the measured VM transient ceiling; calibrate its gain in firmware.
- Confirm NTC placement and calibrate temperature thresholds against measured MOSFET case/junction behavior.
- Tune gate resistors, phase snubbers, and any VM damping or clamp population only from measurements on the assembled PCB.
- Validate AS5047P shaft alignment, external encoder/Hall cable behavior, and feedback-mux reset sequencing.
- Finalize heatsink/chassis contact, board outline, stack-up, copper weights, and fabrication current limits during PCB design.
- Confirm the CP2102N ROM-UART programming workflow; SWD remains the guaranteed programming and recovery path.

## A0 release operating constraints

USB-only service requires a 5 V source that permits at least 500 mA; USB pre-enumeration/suspend load shedding is not implemented. External feedback power is limited to 25 mA and signals to 0–3.3 V. Historical A0 used 2040 uF electrolytic bulk. P3 replaces it with 48 fitted CL32Y106KCVZNWE ceramics (480 uF nominal; approximately 160 uF typical at 42 V before temperature/tolerance/aging) plus six DNP positions and external-bulk pads. The new bank is not capacitance- or ripple-rating-equivalent; measure bus ripple, ringing and capacitor heating before extending the current envelope. The fitted hardware brake backup is approximately 45.9 V rising / 44.2 V falling and requires an installed, adequately rated external resistor. See the release review for the defined 219 J example and first-power-up restrictions.

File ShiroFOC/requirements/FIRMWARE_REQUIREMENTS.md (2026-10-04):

# ShiroFOC firmware requirements — P2 baseline with P3 divider updates

**Baseline:** 27 September 2026, `Manual_Layout_P2/ShiroFOC_Manual.kicad_sch`.
**Revision change:** optional external brake NTC on PC2; status LED moved from PC2 to PC15. The archived Manual_Rebuild project retains the previous pin assignment.
**P3 divider update (4 October 2026):** `Manual_Layout_P3` uses 560 kΩ / 28 kΩ for bus sensing (the nominal ×21 firmware scale is unchanged), and the hardware OV divider now trips nominally at 45.8 V / releases at 44.1 V. P2 files retain their original divider components. The rows and filter timing below describe the revised P3 dividers; other requirements retain the P2 baseline pending revision-specific verification.
**Status:** implementation contract, not implemented or safety-qualified firmware.

This is the current firmware requirements document. It supersedes conflicting instructions in the older A0 bring-up contract, pinout plan and design constraints. **MUST** means required; **PROVISIONAL** means a bring-up starting point that requires measurement before release. An unresolved safety parameter must prevent normal arming, rather than silently receiving a guessed default.

## 1. Hardware the firmware must match

| Item | Current baseline |
|---|---|
| MCU | STSPIN32G4's STM32G431; 128 kB internal program/data flash, 32 kB SRAM |
| Battery target | 10S LiPo, 42.0 V fully charged; separately configured 6S/8S support |
| Current target | Provisional 25 A RMS phase current **with qualified cooling**; not a demonstrated board rating |
| Gate supply | External approximately 10 V: VM → LMR36510 → VCC; SW tied to VM |
| Logic supplies | VCC → MPM3620A → 5V_BAT; USB/battery mux → 5V_SYS → 3V3 LDO |
| Current sensing | Three 0.5 mΩ shunts; external op-amp feedback gain 28; nominal 14 mV/A about VREF/2 |
| Bus measurement | P3: R103 = 560 kΩ (0603, 75 V), R105 = 28 kΩ (0402), both 0.1%; nominal division by 21; R104 removed; R106 = 1 kΩ, C108 = 10 nF |
| Angle | AS5047P absolute-angle SPI3, dedicated bus |
| IMU | BMI323 on I2C2, address 0x68; configuration and data over I²C |
| External feedback | Three buffered 3–5 V single-ended Hall or ABI inputs, selected through TMUX1574 |
| Brake | PB9/TIM17 request ORed with independent hardware overvoltage command |
| Hardware OV backup | P3: nominal 45.8 V on / 44.1 V off using 470 kΩ / 13.3 kΩ and 1 MΩ feedback, all 1%; tolerance and transient overshoot remain to be measured |
| External brake resistor | Provisional 10 Ω, Vishay RH25010R00FE01; thermal rating depends on mounting |
| Brake temperature | Optional 10 kΩ-at-25°C external NTC on J502; PC2/ADC12_IN8; configure actual probe curve |

**FW-HW-01:** Bind the firmware to a board revision and a reviewed schematic/netlist identity. Stop and report a mismatch rather than importing settings from the old reference board. Preserve a generated pin/peripheral map, driver register configuration, configuration schema and test results in the firmware repository.

**FW-HW-02:** The MOSFET symbol/footprint reconciliation and other existing hardware review items remain prerequisites to energizing an assembled board. Firmware cannot establish that the physical board matches the schematic. No firmware setting authorizes 60 V operation, 100 A operation, or a battery configuration inferred from component absolute maximum ratings.

## 2. Persistent BOOT0 configuration and recovery

PB8 is both external index/Hall input and BOOT0. Removing the BOOT button does not change that silicon function.

**FW-BOOT-01 — provision these option bytes:**

| Field | Required setting | Meaning |
|---|---|---|
| `FLASH_OPTR.nSWBOOT0` (bit 26) | **0** | Select BOOT0 from the option byte, ignoring the PB8 level for boot selection |
| `FLASH_OPTR.nBOOT0` (bit 27) | **1** | Select main flash with the setting above |
| NRST mode | Retain external reset function | PG10 must remain usable by SWD connect-under-reset |
| RDP | Level 0 for this development board | Keep debug/recovery available; never program irreversible Level 2 |

ST's HAL names for the first two settings are `OB_BOOT0_FROM_OB` and `OB_nBOOT0_SET`. `nBOOT1` does not determine the main-flash result for this combination; preserve and record its value rather than rewriting unrelated bits. See [ST boot table](https://www.st.com/resource/en/application_note/an5094-migrating-between-stm32f334303-and-stm32g431g474g491-mcus-stmicroelectronics.pdf), table 6, and [ST HAL definitions](https://github.com/STMicroelectronics/stm32g4xx-hal-driver/blob/master/Inc/stm32g4xx_hal_flash.h). The inverted `n...` naming matters.

**FW-BOOT-02:** Program and verify option bytes in the controlled **SWD provisioning process**, preferably with STM32CubeProgrammer. Read the existing option bytes, change only intended fields, perform the required reload/reset, read back, then power-cycle and test boot with external feedback high and low. Use stable control power, stationary motor, inverter disabled and no pending braking requirement. Record the result with the board serial number and firmware version.

**FW-BOOT-03:** These settings persist through loss of power and are not normal RAM variables. Merely writing a GPIO in `main()` is too late to determine that boot's memory selection. Application startup MUST inspect the effective configuration and prohibit arming if it is wrong. Do not automatically rewrite option bytes every boot. A deliberate one-time firmware provisioning routine is possible, but must follow the same disarmed, stable-power, readback and reset procedure.

**FW-BOOT-04:** Retain hardware reset isolation: PC14 mux enable inactive/high, PD2 select low, R307 holding PB8 low. Do not depend exclusively on this isolation instead of provisioning option bytes. Blank/corrupt flash is a recovery case, not a normal flash-boot guarantee. First programming and recovery use SWD; PB8 high will no longer request the ROM bootloader. USB here is a **CP2102N UART bridge**, not a directly wired MCU USB-DFU connection.

**FW-BOOT-05:** Choose and record BOR/PVD settings using the actual MCU supply/clock/flash specifications. Do not invent a BOR code from another STM32 family. Brownout must inhibit torque and flash writes. Retain the option-byte manifest through firmware updates and verify it after programming operations that can affect it.

## 3. Calibration and configuration in nonvolatile memory

**FW-NVM-01:** Use reserved, linker-protected **normal internal flash** for calibration/configuration; no external memory is required for the initial implementation. This is separate from BOOT0 option bytes. Do not put routinely editable calibration in OTP. VBAT is tied to 3V3, so backup RAM/registers are not a substitute for storage across complete power loss.

**FW-NVM-02:** Store versioned records with board identity, motor identity, units, length, monotonic generation, integrity check and a final commit marker. Use two independently erasable storage areas, or a proven wear-levelled journal: keep the old valid record until a new record is written and verified. On interrupted erase/write, recover the newest complete valid record. Verify the exact STM32G431 flash erase/program geometry and ECC rules before choosing addresses; reserve space in the linker and updater. See [ST EEPROM-emulation guidance](https://www.st.com/resource/en/application_note/an4894-eeprom-emulation-techniques-and-software-for-stm32-microcontrollers-stmicroelectronics.pdf).

**FW-NVM-03:** Persist motor pole-pair count, phase order/direction, electrical zero offset, selected feedback type, Hall sequence or ABI scale where applicable, validated gains/limits, battery profile and brake-resistor configuration. Store calibration quality/version and relevant temperature. Never persist “armed”, a live torque request, or automatic permission to resume motion. Re-estimate current offsets with PWM off at startup; a stored offset is a plausibility reference, not proof the live offset is correct.

**FW-NVM-04:** Only save on explicit configuration commit or successful calibration, with wear accounting. No writes from the FOC interrupt and no continuous flash fault logging. Invalid/out-of-range/NaN/CRC-failed data selects an unarmed configuration-required state. Motor identity or schema mismatch invalidates the relevant calibration.

**FW-NVM-05:** Flash erase/program can stall code and interrupts on this MCU. Therefore write/update only with inverter disabled, rotor stationary or mechanically secured, bus stable and no software-braking dependency. “Disarmed” alone is insufficient: an externally driven motor may still regenerate. Defer the write if these conditions cannot be established. Power-fail testing must show recovery of either the old or new record, never a partly accepted record. Preserve calibration across ordinary firmware upgrades, or explicitly invalidate incompatible records.

## 4. Startup, state machine and arming

**FW-STATE-01:** Implement explicit states: `RESET_SAFE`, `SERVICE_ONLY`, `SELF_TEST`, `DISARMED`, `CALIBRATION`, `ARMED`, `FAULT_LATCHED`. CALIBRATION may generate torque and requires its own explicit permission, low limits and abort conditions. No path from reset, restored power, watchdog reset or fault clear may automatically resume motor torque.

**FW-START-01:** Before peripheral initialization, keep TIM1 main-output enable (MOE) cleared; define all six PWM idle levels as inactive and verify complementary-output polarity. PB9 brake request starts low. CAN standby/PB10 remains high. Preload output latches before changing pin modes to avoid enable pulses.

**FW-START-02:** Initialize the 24 MHz HSE/PLL, flash latency and voltage scaling from the exact MCU clock limits. Clock failure must produce a defined inverter-off fault. Keep SWD; configure PB3/PB4/PA15 for SPI rather than competing JTAG/SWO. Set `PWR_CR3.UCPD1_DBDIS = 1` early so USB-C dead-battery loads do not load PB4/PB6. Keep the internal VREFBUF output disabled because VREF+ is externally supplied.

**FW-START-03:** Set PD2 low, configure PC14 as a low-speed open-drain output, then pull PC14 low to enable the input mux. Keep it enabled for VM sensing even when using onboard SPI feedback. Wait **at least 2 ms**, obtain multiple plausible VM samples, and only then accept VM as valid. Mark VM invalid before disabling the mux. Its fourth channel carries the divider regardless of PD2 selection.

**FW-START-04:** Calibrate ADCs and initialize OPAMP1/2/3 for the actual external-feedback networks. With gates off and the motor stationary, acquire offset statistics, check all three channels and validate temperatures/reference voltage. If the motor is being back-driven, wait or enter a defined recovery state; do not learn its current as a zero offset.

**FW-START-05:** Initialize the internal gate-driver I2C3 connection with bounded retries. Apply and read back the board-specific register configuration after every driver power-up/reset, including VM loss while USB keeps the MCU alive. The board uses **external VCC and external 3V3**: configure the documented bypass/disable policy (`POWMNG.VCC_DIS = 1`, `REG3V3_DIS = 1`, standby regulator disabled), using the protected-register sequence and checking resulting READY/UVLO behavior. Do not execute the old “raise internal VCC from 8 V to 10 V” startup procedure. Hardware wiring must already permit safe power-up before firmware runs. Verify this sequence on the prototype; do not use standby modes until external-supply behavior is qualified.

**FW-START-06:** Enable driver interlocking, VDS protection, deadtime and the verified timer-break sources before any gate activity. Check READY, nFAULT, reset status and readable configuration. A high READY alone is insufficient. Do not repeatedly clear a fault to force startup. Establish bootstrap precharge using a bounded, tested sequence with fault monitoring; constrain high-side on-time and PWM modulation to preserve bootstrap refresh and current sampling.

**FW-ARM-01:** Arming requires a fresh explicit command, valid boot/configuration, completed self-test, valid position/current/VM/temperature, verified protection configuration, valid battery/motor limits, and a qualified regeneration-energy path. Require zero initial torque and ramp limits. USB-only operation allows service/configuration but no inverter gate commands. A successful I²C read alone does not prove motor power is present.

## 5. Peripheral ownership and acquisition

| Function | Pins/resources | Required behavior |
|---|---|---|
| Inverter | TIM1; internal PE8–PE13 | Complementary PWM; hardware break; no reuse for unrelated PWM |
| Driver | I2C3 PC8/PC9; PE7 WAKE; PE14 READY; PE15 nFAULT | Reserved internal connections; verified AF/break mapping |
| Current U | PA1 +, PA3 −, PA2 out | OPAMP1 external feedback; ADC1_IN3 |
| Current V | PA7 +, PC5 −, PA6 out | OPAMP2 external feedback; ADC2_IN3 |
| Current W | PB0 +, PB2 −, PB1 out | OPAMP3 external feedback; ADC1_IN12 |
| VM | PA0 | ADC1/2_IN1; mux validity required |
| NTC U/V/W | PC3 / PC0 / PC1 | ADC channels 9 / 6 / 7 |
| Brake NTC | PC2 / STSPIN pad 11 | ADC1 or ADC2 channel 8; regular slow acquisition, no GPIO output |
| Status LED | PC15 / STSPIN pad 5 | Active-low open-drain output, low speed; R304 = 2.2 kΩ; not spare GPIO |
| Angle | PB3 SCK, PB4 MISO, PB5 MOSI; PA15 CS | Dedicated SPI3, mode 1; GPIO CS |
| IMU | PC4 SCL, PA8 SDA; PA4/PA5 interrupts | I2C2, open-drain, 400 kHz; 0x68; EXTI4/5 |
| External feedback | PB6/PB7/PB8 | TIM4 Hall or quadrature; index handled explicitly |
| External sensor supply fault | PC13 / pad 3 | EXT_SENSOR_FAULT_N, active-low input; optional EXTI13; external 10k pull-up to3V3 |
| Input mux | PD2 / PC14 | Select external inputs / active-low enable |
| Brake request | PB9 | TIM17_CH1; do not use TIM4_CH4 here |
| CAN | PA11 RX, PA12 TX; PB10 STB | FDCAN1; TX recessive before releasing standby |
| Service UART | PA9 TX / PA10 RX | USART1 through CP2102N |
| Debug | PA13 / PA14; PG10 NRST | SWD and reset retained |

**FW-ADC-01:** Three op-amps do not provide three simultaneous ADCs. ADC1 is shared by U and W. Schedule synchronized conversions in valid low-side conduction windows; account for deadtime, blanking, op-amp settling, ADC acquisition and channel switching. Reject clipped/out-of-window samples. Reconstruct the third current from two valid samples only under the appropriate three-wire motor assumptions. Limit modulation when sampling windows become too short. Slow VM/NTC/reference measurements must not disrupt current acquisition.

**FW-ADC-02:** Nominal conversion is `I_phase = (V_adc − V_offset) / 0.014`, with sign verified physically for each phase. Use measured VREF and calibrated scaling. Define whether every API limit is instantaneous peak, RMS, dq amplitude or battery current. The 25 A RMS target corresponds to about 35.4 A sinusoidal peak; neither the ADC's approximate ±100 A range nor a MOSFET headline rating is a permissible current limit. Start commissioning at 1–2 A instantaneous and raise limits only against recorded tests.

**FW-OCP-01:** Provide an ISR-independent fast inverter shutdown using verified on-chip comparator/TIM1-break routing and STSPIN VDS protection. The previous proposed COMP1/2/4 paths observe biased op-amp **inputs**, not the amplified ADC outputs. Re-derive DAC thresholds, polarity, offset sensitivity, common-mode validity and exact internal routing from the schematic and MCU reference manual. Do not copy the old illustrative “60 A / DAC code 107” into a release. This path is not automatically a precise bipolar current limit. Require software limits for both polarities and demonstrate low-energy fault injection into each implemented hardware trip path. VDS protection is not a calibrated phase-current measurement.

**FW-ANGLE-01:** Check AS5047P parity, error flags, magnetic diagnostics, transaction timeout, sample age and physical angle/speed plausibility. Account for pipelined replies and angle latency; use mechanical angle × pole pairs + calibrated electrical offset with the verified sign convention. Absolute readout removes cumulative missed ABI counts, but invalid/stale readings remain faults. Do not invent a fallback Hall/sensorless mode on loss of angle. A bounded stale-sample policy must be explicitly validated against maximum electrical speed.

**FW-IMU-01:** Configure and read BMI323 entirely over I²C, including its two dummy read bytes. Start with a 1 ms sample period and nonblocking transfers. IMU traffic/recovery must not block the FOC loop or gate-driver safety handling. For motor-only control, IMU failure may be a reported degraded mode; if a robot's balance/stability controller depends on it, that application must specify a timely safe-stop policy.

**FW-EXT-01:** Hall and ABI are separately configured modes. For Hall, validate the calibrated sequence, illegal states and transition timing. For ABI, validate counts/revolution convention, direction, rollover, index behavior and electrical-angle initialization: incremental data alone gives no absolute angle after power-up. Select PD2 high only while disarmed with timer state reset and inputs checked. Switching sources must not step the torque angle. The JP601 voltage jumper and optional 4.7 kΩ Hall pull-ups are hardware configuration, not software-selectable features.

**FW-EXT-02 — protected sensor supply:** U604 TPS2553DBVR feeds J601.1 and any fitted Hall pull-ups after JP601. It is always enabled when the selected supply is present; firmware does not enable or reset this switch. ILIM is tied to IN for a75mA nominal limit (specified50–100mA); normal total sensor/pull-up budget stays25mA. Configure PC13/pad3 as a digital input named `EXT_SENSOR_FAULT_N`, never drive it. R60410k pulls its open-drain fault output to3V3; TP1023 exposes the same net. PC13 is no longer SPARE_GPIO_3. PC15 remains spare.

**FW-EXT-03 — fault response and recovery:** Sample the fault before arming and monitor during operation (EXTI13 and/or bounded polling). If external Hall/ABI feedback is selected, an asserted fault must inhibit arming or disable motor PWM and latch a reported sensor-supply fault; do not keep applying torque using the lost position feedback. Hardware current limiting is immediate on the device's response timescale; FAULT reporting is internally deglitched (7.5ms typical), so it is not an instantaneous short detector. Retain Hall/ABI validity/time-out checks. Automatic recovery of the switch or a deasserted FAULT must not automatically resume motor drive: require valid feedback and an explicit re-arm. While using the independent onboard magnetic encoder, report/isolate the external accessory fault according to application policy; do not invent an automatic feedback-source swap.

**FW-EXT-04 — scope and commissioning:** FAULT high does not prove that JP601 is bridged, that a sensor is connected or that its supply is healthy; the signal reports switch faults, not every cable/sensor failure. Test shorts at J601.1 toGND at both3.3V/5V selections, including power-up into a short, USB-only operation, maximum intended control load and fault removal. Verify MCU supply stays above its brownout threshold, thermal cycling remains acceptable, and firmware does not auto-rearm. Protection is for the low-voltage accessory power branch, not motor/VM shorts into Hall pins. User CAD/PCB tasks remain deferred.

## 6. Brake chopper, battery profiles and regeneration

**FW-BRAKE-01 — separate the two jobs:** Firmware manages normal bus rise using battery-profile thresholds. The comparator marked **“Capacitor un-exploder”** is an independent last-resort board-bus backup, nominally 45.9/44.2 V. It is **not a BMS**, cell monitor, guaranteed capacitor protector, or appropriate normal cutoff for 6S/8S packs. The board does not measure individual cell voltages or provide a battery-disconnect switch.

**FW-BRAKE-02:** Require an explicitly selected chemistry/cell-count profile; do not infer 6S/8S/10S solely from pack voltage because their operating ranges overlap. Store full-pack voltage, charge acceptance policy/current bound, undervoltage derate/cutoff, software brake thresholds, fault threshold and hysteresis. A **10S bench starting example** is brake on near 43.0 V and off near 42.5 V; these are PROVISIONAL, not battery charge limits. Derive 6S/8S settings separately from their 25.2/33.6 V full-charge levels, sensing error and tested transients. A missing profile prevents arming.

**FW-BRAKE-03:** Choose thresholds so a fresh valid pack does not continuously discharge into the resistor, while the worst-case software regulation/overshoot remains below the earliest hardware trip and the qualified board limit. Use the comparator's tolerance bounds, not just its nominal 45.9 V. Do not raise the backup target to 60 V. The hardware threshold cannot be changed by firmware.

**FW-BRAKE-04:** Schedule VM acquisition and brake control independently of host traffic. Apply bounded duty, hysteresis or a stable control law with anti-windup; avoid rapid chatter and duty jumps. The divider/1 kΩ/10 nF network has an approximate **277 µs** time constant in P3 (560 kΩ ∥ 28 kΩ, plus 1 kΩ, with 10 nF; neglecting mux resistance and ADC loading) before ADC and software delays. Initial VM sampling at least 1 kHz is a scheduling starting point, not proof of sufficient response. Derive and measure the total reaction budget using worst-case net regenerative current and effective bus capacitance: `dV/dt ≈ I_net / C_bus`. Include filtering, conversion, scheduling, gate-drive and resistor response. Increase sampling/control rate or restrict braking energy as required by that budget.

**FW-BRAKE-05:** For the provisional 10 Ω resistor, use `I_on = Vbus/R`, `P_average ≈ duty × Vbus²/R` and `E = integral(P dt)` in duty/energy limits. Full-on examples: 42 V → 4.2 A / 176 W; 46 V → 4.6 A / 212 W. Its “250 W” rating requires specified heatsinking; the documented free-air rating is 100 W at 25°C. Account for tolerance, ambient, cooling, pulse duration and repeated stops. P2 has an **optional brake-resistor NTC input**, but still no brake-current or power-resistor continuity sensor. A connected NTC does not prove that the power resistor is connected. Treat calculated energy as an estimate and require an installation/commissioning record; do not claim software detects an open resistor.

**FW-BRAKE-06:** If predicted regeneration exceeds the battery's allowed acceptance plus the qualified resistor capacity, reduce requested regenerative torque/deceleration before bus voltage becomes critical and notify the higher-level controller that the requested stop cannot be sustained. A larger motor or resistor wattage label does not automatically increase the existing chopper's capability. A BMS may abruptly stop accepting charge; the local bus can then rise. Do not assume a connected battery or laboratory supply will absorb energy. RC LiPo operation requires explicit configuration acknowledging the absence of per-cell protection; bus regulation cannot replace it.

**FW-BRAKE-07:** Inverter disable and brake disable are separate operations. On an inverter fault, stop commanded motor switching immediately, but continue software bus protection when its measurements, supply and execution remain trustworthy. A coasting or externally driven motor can still regenerate through body diodes. Do not implement a blanket “stop every PWM” fault handler that unnecessarily kills a healthy chopper.

**FW-BRAKE-08:** The hardware OV command can hold the chopper on despite PB9 being low or the MCU being reset, provided its supplies remain available. It has no routed MCU status input, so firmware cannot directly know that it fired. Software cannot override it or guarantee resistor thermal shutdown. If VM sensing or software control is invalid, clear the software brake request, latch the inverter off and report loss of normal bus control; the hardware backup is the remaining limited protection, not a guarantee. Resistor overheating and bus overvoltage can conflict: reduce energy generation early and require the system's mechanical/energy-management response rather than promising a firmware-only solution.

## 7. Fault handling, timing and communication

**FW-FAULT-01:** Hardware breaks must latch inverter outputs inactive without depending on an interrupt. Disable automatic restart. ISR/foreground code records the cause; fault clear requires stable healthy conditions, explicit acknowledgement and a separate fresh arm command. A fault cannot erase the history before it is captured. Fault recovery never restores a stored torque command.

| Condition | Minimum required response |
|---|---|
| Hardware overcurrent, VDS trip, nFAULT or loss of driver readiness | Hardware inverter disable where supported; latch fault; retain healthy bus protection |
| ADC overrun, invalid current window, implausible current or FOC deadline miss | Reject bad data; apply validated bounded fallback or latch off; no indefinite stale control |
| Invalid/stale angle, illegal Hall sequence | No uncontrolled commutation; latch inverter off after the validated detection budget |
| Bus OV/UV, VM loss or driver reset while USB remains | Restrict torque / trip as configured; invalidate driver state; repeat startup on return |
| NTC open/short, implausible temperature or overtemperature | Inhibit arming or derate/trip as defined; do not interpret a broken sensor as a cold board |
| Command timeout, CAN bus-off or service disconnect | Apply configured bounded stop if feedback and energy capacity permit; otherwise inverter off; no automatic re-arm |
| Watchdog reset, HardFault, brownout or clock failure | Inactive inverter outputs; reset into unarmed state; log recoverable cause |
| Brake energy budget exhausted / resistor installation unknown | Inhibit or restrict regeneration; latch/report as appropriate; do not assume braking torque is available |

**FW-TEMP-01:** Current NTCs are nominal 10 kΩ at 25°C, B3380, to ground with 4.7 kΩ pull-ups. Use the exact selected part's curve, tolerance and measured ADC scaling. Open tends toward VREF, short toward ground. Set plausibility thresholds outside legitimate cold/hot extremes. Use the hottest valid phase reading and validate thermal lag to MOSFET junctions. Release derate/trip temperatures require measured board/cooling evidence; the NTC is not a direct junction thermometer.

**FW-TEMP-02 — optional brake probe:** J502 pin 1 is the thermistor signal and pin 2 is GND. R511 = 10 kΩ to 3V3, R512 = 4.7 kΩ series into PC2, C505 = 100 nF to ground, D505 = BAT54S rail clamps. Nominal transfer is `Vadc = V3V3 × Rntc / (10000 + Rntc)`; the series resistor is outside the DC divider when input/clamp leakage is negligible. Use actual 3V3-to-VREF scaling, the selected probe's resistance/temperature curve and tolerances; do not reuse the phase sensors' 4.7 kΩ pull-up or assume their B3380 curve. The external probe is not yet selected. Account for diode leakage over board temperature in coarse threshold validation.

**FW-TEMP-03:** Persist `brake_ntc_present`, probe curve/calibration, valid range, derating threshold, overtemperature threshold and hysteresis. Without a probe explicitly configured, report temperature as unavailable and retain conservative resistor energy/duty limits; an open connector is allowed in that mode. If configured present, an open/high, short/low, stale or implausible reading is a sensor fault, never a cold resistor. Validate fault thresholds against legitimate hot/cold extremes. Do not automatically decide the probe is absent after a fault.

**FW-TEMP-04:** Configure PC2 analog mode without pulls; sample channel 8 in the slow ADC schedule without disturbing injected phase-current measurements. Start with 20 Hz monitoring, adequate ADC acquisition time, and at least 10 ms settling after the supply/reference becomes valid (worst nominal external RC time constant 1.47 ms). Validate end-to-end lag including the sensor attachment and software filtering. Use resistor temperature to derate regeneration early and inform the host. The surface probe does not protect against a short energy pulse before its temperature catches up: retain energy integration and pulse limits. Never disable a needed bus clamp merely because the resistor is hot; follow FW-BRAKE-06/07/08 and request system-level energy reduction.

**FW-LED-01:** PC15 now drives D301 through its cathode; low turns it on. Preload high/off, use low-speed open-drain mode, and leave the LSE oscillator/competing backup-domain pin functions disabled. R304 = 2.2 kΩ bounds LED current below approximately 1.65 mA at 3.6 V even for a shorted LED; include PC14's pull-up current in the PC13–PC15 shared 3 mA sink budget. These pins must not source LED current. PC2 must never run the previous status-LED code.

**FW-TIME-01:** Begin with PROVISIONAL 20 kHz center-aligned PWM/FOC and 500 ns programmed deadtime; confirm the actual timer clock, nonlinear deadtime encoding, polarity and measured gate waveforms. At 20 kHz the FOC period is 50 µs. Establish worst-case execution time with margin and detect missed deadlines. SPI angle reads at approximately 5 MHz require about 6.4 µs for two 16-bit frames plus required gaps/overhead; do not budget zero latency. Keep flash operations, printf, packet parsing and blocking sensor retries outside this path.

**FW-TIME-02:** Use an independent watchdog and bounded bus/DMA timeouts. Feed the watchdog only after required control/safety tasks demonstrate progress, not unconditionally in an interrupt. Specify timeout values and worst-case detection-to-gate-off measurements in the release configuration. Debug halt is hazardous: only halt live firmware with motor power safely limited/removed; timer/watchdog freeze settings are not a complete safety strategy.

**FW-COMMS-01:** CAN and UART share validated commands and configuration semantics. Enforce finite values, ranges, units, command ownership, sequence/freshness and an explicit command timeout. Reject malformed/oversized packets without disturbing real-time control. No boot packet, reconnect, stale queue or restored NVM may arm the motor. Keep CAN TX recessive before releasing standby. Report board/firmware ID, active limits, reset/fault reason, VM, currents, temperatures, angle age/errors and estimated brake duty/energy.

**FW-COMMS-02:** CAN termination is manually configured in this revision. R802 (120 Ω) is fitted on every board; JP801 is an open solder jumper, closed only on boards at the two physical bus ends. Firmware cannot change or directly detect its state; record it as installation configuration. All four TMUX1574 channels currently have assigned functions. Any future software-controlled termination requires a separately reviewed circuit and reset/fault policy. The 3.3 V-powered TCAN3413 interoperates with 5 V-powered high-speed CAN transceivers; this is not a selectable bus-supply setting.

## 8. Implementation and acceptance gates

The firmware agent MUST supply a requirements-to-test checklist using these IDs. Passing compilation or simulator tests does not qualify the assembled power stage.

1. **Static configuration:** exact target/clock/AF map; no peripheral clashes; linker-reserved flash; reviewed PWM polarity, reset levels, break routing, external-supply driver registers and fault state machine.
2. **Host/unit tests:** angle wrap/parity/error handling; CRC/journal power-interruption recovery; range/NaN rejection; current units/scaling; NTC endpoints; battery-profile selection; brake saturation/energy accounting; fault/arming transitions and communication timeouts.
3. **Control power only:** SWD provisioning/readback; flash boot with feedback high/low; erased/corrupt configuration; USB-only inhibition; simulated VM disappearance/return; no output pulses during reset or watchdog recovery.
4. **Low-energy hardware tests:** measure rails and ADC calibration; prove each hardware break without an ISR; check comparator thresholds, driver faults, deadtime, bootstrap refresh and low-side sample windows. Inject faults with safe low-energy stimuli rather than high-energy intentional shorts.
5. **Brake tests:** qualified external resistor installed; measured software and hardware thresholds, including MCU held reset; inspect bus and gate peaks, resistor energy and cooling. Simulate a non-absorbing source or controlled disconnect. Demonstrate continued bus control during an inverter fault where possible.
6. **Motor tests:** unloaded 1–2 A initial operation; current/angle sign and electrical zero; bounded calibration; encoder disconnect/stale replies, Hall faults, I²C stuck bus, CAN timeout and thermal sensor faults. Verify that IMU recovery cannot stall FOC.
7. **Release envelope:** record cooling, ambient, motor/load inertia, voltage range, allowable regeneration, current limits, PWM range, response latency and thermal limits. Increase toward 25 A RMS only after measurements support it. Repeat persistence/update tests with interruption at every write/erase/commit stage.

### Parameters that must be resolved before normal arming

- Validated phase peak/RMS and battery charge/discharge limits, comparator/DAC thresholds and VDS settings.
- Battery-specific UV/OV and brake thresholds, tolerance margins and energy-sink configuration.
- Thermal derate/trip limits; resistor continuous/pulse energy and cooling model.
- FOC/angle/VM fault-detection deadlines, watchdog and command timeout, measured brake response budget.
- PWM/deadtime/modulation limits and valid ADC sampling windows.
- Approved option-byte manifest, BOR/PVD settings, flash partition and update/recovery procedure.

A restricted, explicitly entered commissioning build may use documented low-energy provisional limits to measure these values. It must not present itself as a qualified 25 A operating profile.

## 9. Evidence and precedence

- [Current sensor interface revision and exact connectivity checks](../Manual_Rebuild/review/sensor_interface_revision/README.md).
- [Half-bridge and current-amplifier decisions](../Manual_Rebuild/review/bridge_current_parts/README.md).
- [Brake topology, values and resistor limitations](../Manual_Rebuild/review/brake_parts/README.md).
- [External-supply power revision](../Manual_Rebuild/review/cascaded_power/REVIEW.md).
- [MCU review](../Manual_Rebuild/review/MCU_PIN_REVIEW.md): analog/internal resource evidence; shared-SPI/BOOT-button portions are superseded.
- [STSPIN32G4 datasheet](https://www.st.com/resource/en/datasheet/stspin32g4.pdf): external supplies, internal connections, protected driver registers and memory.
- [STM32G4 reference manual RM0440](https://www.st.com/resource/en/reference_manual/rm0440-stm32g4-series-advanced-armbased-32bit-mcus-stmicroelectronics.pdf): firmware agent must verify exact register routing, flash geometry and option-byte procedures for STM32G431. The full manual was not re-audited in creating this document.

Current native schematic and explicit later user-approved changes take precedence over historical design notes. If they disagree with this contract, report and reconcile the discrepancy before enabling torque.

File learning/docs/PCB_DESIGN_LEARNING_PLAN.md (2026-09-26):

# Understanding ShiroFOC PCB Design Decisions

## Purpose

Move from following PCB rules to understanding the system well enough to predict what changes when a component value or its placement changes.

This plan is tailored to a mechanical engineer specialising in robotics, control theory and mechatronics. It connects familiar concepts—energy storage, impedance, disturbances, resonance, damping and transfer functions—to the actual board.

## Goal for the weekend

Build an interactive model of our board, supported by a short learning notebook. By the end, be able to explain:

- What capacitors do during motor switching.
- What changes when capacitance increases or decreases.
- Why placement can matter as much as capacitance.
- What heats capacitors, MOSFETs and shunts.
- Which decisions can be justified analytically, and which need measurements.

Use understandable approximations and make every assumption visible. Models support design decisions; their precision should not be overstated.

## 1. Establish the actual system

Extract the relevant values from the schematic and intended operating conditions:

- Battery voltage and supply cable length.
- Motor resistance and inductance, or a clearly labelled range if unknown.
- Phase current and PWM frequency.
- MOSFET switching characteristics.
- Capacitor values and approximate resistance and inductance.
- Brake circuit thresholds.

**Deliverable:** one annotated power-path diagram and a table of model inputs. Mark every number as a design value, datasheet value or assumption.

## 2. Start with one switching half bridge

Before modelling all three phases, make one understandable.

Show current paths during each switching state, including when motor current continues flowing while a MOSFET is off.

Plot together:

- PWM command.
- Motor voltage and current.
- Current drawn from the supply.
- Current entering or leaving the local capacitor.

Answer the key question: **why can motor current be fairly smooth while the supply sees pulses?**

**Deliverable:** an interactive switching example with adjustable duty cycle, frequency and motor inductance.

## 3. Model the supply and capacitor bank

Build the model in stages so each added detail has an obvious purpose.

| Model | What it teaches |
|---|---|
| Ideal capacitor supplying a current pulse | How capacitance limits voltage change |
| Add capacitor resistance | Instantaneous voltage drop and capacitor heating |
| Add cable inductance and resistance | Supply-voltage oscillation and damping |
| Add capacitor and connection inductance | Why large capacitance alone cannot stop fast spikes |
| Separate nearby and distant capacitors | Why local and bulk describe different jobs |

Start with the familiar relationships:

- `i = C × dv/dt`
- `v = L × di/dt`

Derive the relevant impedance and transfer functions. Explain what their poles and frequency responses mean physically.

**Deliverable:** time-domain plots alongside impedance/Bode plots of the same system.

## 4. Compare concrete capacitor choices

Use our board's operating range to compare:

- The existing three-electrolytic arrangement.
- Several sizes of ceramic-only bank.
- A ceramic bank with an optional external electrolytic.
- The same capacitance placed close to versus far from the MOSFETs.

For each option, plot:

- Bus voltage variation during PWM.
- Capacitor current and estimated heating.
- Response to a sudden load change.
- Connection/startup transient.
- Effective ceramic capacitance as operating voltage increases.

Separate switching pulses from braking energy: they occur on different timescales and may need different solutions.

**Deliverable:** a comparison dashboard where changing a value visibly changes the outcome. Do not assume moteus's capacitor count is automatically correct for our board.

## 5. Connect the electrical model to PCB placement

Translate the plots into actual layout decisions:

- Which current loops must be small.
- Where each capacitor bank belongs.
- Why a narrow connection can undermine a large copper area.
- How gate resistance changes switching speed, losses and ringing.
- Why current-sense connections must avoid shared power-current paths.
- Why MCU decoupling needs short connections to both supply and ground.

**Deliverable:** annotated views of our PCB, with each placement rule linked to a model or waveform.

## 6. Extend the approach to sensing and control

Once the power path makes sense, examine:

- Shunt resistance: signal size, heat and measurement range.
- Amplifier gain: sensitivity versus clipping.
- ADC filtering: noise reduction versus delay.
- PWM-synchronised sampling: avoiding switching disturbances.
- How measurement delay affects the current-control loop.

**Deliverable:** filter response and sampling plots using our actual component values.

## Suggested weekend structure

| Session | Focus |
|---|---|
| Saturday morning | Current paths and one half bridge |
| Saturday afternoon | Capacitor and supply models; interactive comparisons |
| Sunday morning | PCB placement, switching and sensing |
| Sunday afternoon | Choose design values and document the reasoning |

## Teaching format

Use a guided notebook and interactive plots rather than a large presentation. Each section follows:

1. A concrete question about our board.
2. The learner's predicted outcome.
3. A simple model and plot.
4. The physical explanation.
5. The resulting design decision.

Define electrical terminology in plain language when it first appears. Connect equations to physical current paths and observable waveforms, rather than presenting unexplained rules of thumb.

## Final outcome

Produce a short decision record for each important choice:

> We chose this value and placement because this model predicts this behaviour, under these assumptions.

The result should be something the learner can understand, challenge and reuse on future designs.

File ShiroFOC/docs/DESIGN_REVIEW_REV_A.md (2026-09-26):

# ShiroFOC A1-Drawing / A0 electrical release review

**Release scope: ready to begin first-prototype PCB layout in KiCad 9.** This release contains a complete schematic and resolved footprints. PCB routing, fabrication release, firmware implementation, and hardware qualification are subsequent work. The 18–42 V and 25/40 Arms objectives are design targets, not demonstrated ratings.

Electrical review date: 2026-09-15. Connected redraw review: 2026-09-16; see [redraw review](SCHEMATIC_REDRAW_REVIEW.md). Review method: manufacturer documentation, circuit calculations, KiCad 9.0.4 ERC/export, actual PCB footprint loading, full pin/net comparison, and rendered-sheet inspection. This is an agent-assisted engineering review; no human sign-off, SPICE switching simulation, STM32CubeMX run, or hardware test is represented as completed.

## Release evidence

The authoritative artifacts are in `ShiroFOC_KiCad/outputs/`:

| Gate | Result / evidence |
|---|---|
| Native hierarchy | Root plus 11 functional sheets; editable `.kicad_sch` and local `.kicad_sym` |
| Electrical rules | 0 violations across all 12 sheets; `erc_rev_a.json`; no ERC exclusions |
| Connectivity | 260 references, 148 connected nets, 761 symbol pins, including 42 explicit NC pins; `validation_report.json` |
| Footprints | 44 distinct footprint types loaded by `pcbnew`; all symbol pin numbers resolve to package pads; `footprint_audit.json` |
| Physical pad traceability | 895 pad/aperture entries, including repeated thermal-pad numbers and paste-only apertures; `footprint_pad_audit.csv` |
| Assembly | Complete ungrouped BOM including 18 explicit DNP references; native DNP attributes match BOM |
| Visual inspection | Every rendered PDF page; exact reviewed PDF hash in `visual_review.json` |
| Reproducibility | Native build, KiCad exports and checks scripted; `release_manifest.json` hashes the released sources and artifacts |
| Redraw equivalence | Every physical net partition, value, footprint, MPN and DNP state matches the frozen A0 release; local net-name changes are recorded |

ERC uses meaningful input/output/power types for ICs. Power flags identify external connector sources, passive-filtered supply outputs, and internal bootstrap supplies. They do not establish regulator stability or safe transient behavior. Analog MOSFET/shunt paths require the separate pin and package checks.

## Corrections incorporated

- Corrected CSD88599 side-pad numbering and VIN exposed-pad assignment; corrected the brake MOSFET to TI's Q5A copper/stencil pattern. A similarly sized generic SON footprint was electrically incompatible.
- Corrected TLV755 **DYD** land pattern and ground thermal pad. DYD is the thermally enhanced five-lead package; the exposed pad is intentionally numbered 2/GND.
- Corrected diode polarity, crystal pads 1/3 versus case pads 2/4, CAN ESD pin count, and high-frequency DC-link return placement.
- Completed all CP2102N QFN20 physical pins, including pins 10–14. VDD and VREGIN share the external 3V3 rail in documented regulator-bypass mode; UART and MCU no longer have independently sequenced logic rails.
- Added matched bipolar current-sense bias: 1 kΩ inputs, 28 kΩ feedback, and two 56 kΩ bias resistors per phase, all 0.1%. Zero current is midscale.
- Used TMUX channel 4 to isolate the live VM divider from an unpowered MCU. Both inputs carry the same divided voltage, so feedback-source selection does not alter VM sensing.
- Isolated the external-feedback ESD rail from 3V3 with its own 100 nF capacitor. External signal support remains **0–3.3 V**, including while board power is off.
- Assigned PB10 to CAN_STB, with a standby pull-up and recessive TX pull-up. Removed the PB8/BOOT0 test-point stub.
- Added a fitted TLV3012B overvoltage comparator, diode-OR control of the brake driver, and 100 V flyback diode across the external brake connection. The comparator works without executing MCU firmware when 3V3 and VCC are present.
- Assigned documented Wurth 74437349220 inductors to both buck converters, including the manufacturer's central copper keepout. Replaced the obsolete bulk-capacitor MPN with Panasonic EEVFK1J681M.

## Electrical review and operating envelope

### Current sensing and protection

`VOUT = VREF/2 + 28 × (VSENSE_P − VSENSE_N)`. With 0.5 mΩ shunts, gain is 14 mV/A: −80/0/+80 A gives 0.53/1.65/2.77 V at VREF=3.3 V. The shunt dissipates 0.8 W at 40 Arms and 3.2 W instantaneously at 80 A, subject to its terminal-temperature rating and pulse curve. The amplifier's calculated resistor-only zero-current offset spans 1.6436–1.6564 V. Calibrate actual offset/gain and temperature drift.

COMP1/2/4 observe PA1/PA7/PB0. Their positive-input voltage is `(56 × 0.0005 × I + VREF)/58` when the negative Kelvin terminal is near analog ground. A nominal +60 A threshold is 85.86 mV, about code 107 of a 12-bit DAC at 3.3 V. This is an initial engineering target, not a guaranteed trip current: comparator offset, DAC accuracy, filtering, shunt tolerance, and temperature require calibration. These are **one-sided** trips; negative-current limits also need ADC supervision. Preserve VDS protection as the independent short-circuit mechanism. SCREF ≈0.30 V is a VDS fault threshold, not an accurately calibrated phase-current limit.

The internal comparator and timer-break path acts without CPU intervention **after firmware configures it**. It is not active protection in a blank MCU; reset keeps PWM inactive instead. See [firmware contract](FIRMWARE_BRINGUP_CONTRACT.md).

### Bus, gate drive and DC link

The VM divider is 540 kΩ / 27 kΩ: 2.00 V at 42 V and 2.857 V at 60 V. Its nominal RC time constant is 267 µs; allow at least 2 ms after enabling the mux. A 60 V divider calculation does not authorize 60 V bus operation.

The three 680 µF capacitors store about 1.80 J at 42 V. Their summed nameplate ripple rating is only **5.07 Arms at 100 kHz**, before temperature/frequency correction and unequal sharing. This is a potentially limiting item for the 25/40 Arms goal. Measure capacitor ripple and temperature during the current ramp; additional parallel bulk capacitance or a lower operating-current limit may be necessary. The PCB must preserve access to VM/GND for an external low-inductance capacitor bank during characterization.

STSPIN VCC starts at 8 V; firmware selects 10 V. The 22 µH L301 is a deliberate prototype substitution for ST's typical 18 µH example, with ample saturation-current margin; verify startup, regulation and ripple on hardware. The external 5 V converter also uses 22 µH. LMR36510 output is approximately 5.016 V from its 100 kΩ/24.9 kΩ divider. Review effective ceramic capacitance at operating bias during procurement.

Use 20 kHz initial center-aligned PWM, interlocking enabled and a conservative initial MCU deadtime (500 ns, then characterize). For a conservative 56 nC per MOSFET, six gates at 20 kHz consume about 6.72 mA average charge current. A 100 nF bootstrap capacitor loses 0.56 V for 56 nC before leakage and DC-bias derating. Enforce a low-side refresh interval; 100% static high-side duty is unsupported. TI's 4.7 Ω GH / 0 Ω GL starting resistors and separate gate-source pull-downs are fitted. Independent diode-assisted turn-on/turn-off paths from the early wishlist are not populated in this revision; per-gate resistor substitution and DNP phase snubbers provide tuning.

### Brake energy and overvoltage

Nominal hardware thresholds are **45.92 V rising / 44.21 V falling**. The conservative component-corner estimate is 44.19–47.51 V rising and 42.58–45.96 V falling, including reference tolerance plus extra temperature drift allowance, comparator offset/hysteresis, resistor tolerances and output swing. It does not include wiring inductance or dynamic overshoot. Firmware should begin normal braking earlier (43 V starting point for 10S); stop motoring on overvoltage and control regenerated energy.

Defined prototype example: a 0.01 kg·m² load at 2,000 rpm contains 219 J. A **10 Ω external resistor**, at least **250 W on its specified heatsink** and independently rated for **500 J over 5 s**, covers this example with energy margin. At 48 V it draws 4.8 A and dissipates 230 W. This does not cover gravitational work, externally driven motion, repeated stops without cooldown, or every motor. Select the actual resistor from the application's worst energy and repetition rate before regenerative operation.

Use short twisted brake leads. D504 (100 V / 5 A) recirculates lead inductance; it does not dissipate the motor's sustained regenerative energy. If the resistor is open/absent, braking is unavailable. A shorted resistor is a destructive fault unless the upstream fuse/current-limited source clears it. The backup also cannot work with VCC or 3V3 absent. No battery-reverse or onboard precharge protection is claimed.

### Control power and interfaces

The planning allowance is 250 mA at 3V3 (320 mA during a CAN bus fault), including 25 mA maximum external-feedback load. LDO loss is about 0.488 W at 5.25 V input and 250 mA, or 0.624 W during that fault allowance. Connect the DYD thermal pad and validate junction temperature, especially in an enclosed hot power stage. The 1 A buck and 500 mA LDO have current margin; thermal margin depends on layout.

USB-only service requires a 5 V source that permits at least 500 mA. The board does not implement USB pre-enumeration/suspend load shedding or USB-PD/current-advertisement control. Do not claim arbitrary legacy PC-port bus-power compliance. Use an appropriately powered service source/hub, or a service setup that provides the required current allowance. CP2102 configuration must match the intended self-/bus-powered mode and descriptor current.

The 5 V mux has reverse-current blocking and selects USB when both valid inputs are present. The STSPIN power stage stays unpowered with USB alone. SWD VTREF is sense-only; a debugger must not feed 3V3. J601 supply is an output, not an external power-injection point. External inputs above 3.3 V or negative voltages are unsupported; the mux is not a level translator.

## Fault and startup disposition

| Condition | Hardware behavior / required response |
|---|---|
| Erased MCU, reset, or USB alone | Inverter inputs default low; mux disabled; PB8 low; CAN standby. Brake input is low below its OV threshold; no brake gate drive without VCC. |
| Battery alone / both sources | External 3V3 powers logic; VM separately powers VCC. Mux prefers valid USB. Validate power switchover brownout behavior. |
| VM disappears and returns with USB attached | MCU survives; invalidate motor state and reinitialize the STSPIN driver, VCC setting and protections before torque. |
| Regeneration / BMS opens / nonsinking PSU | Fit and qualify the external brake resistor. Hardware OV backup may assert during reset. Neither the DNP TVS nor a battery is assumed to absorb all energy. |
| Bus hot-plug | External fuse and precharge/current limiting required for first tests. D101/R102/C107 are unqualified tuning positions. |
| Phase short / stall | Configured comparator/TIM1 break plus STSPIN VDS faults; latch off. Hardware short-circuit performance requires measured testing before high energy. |
| Feedback loss / invalid Hall states | Inhibit PWM, then isolate feedback if needed. Disabling the mux also invalidates VM sensing. |
| NTC open / short | Read near full-scale / zero; declare fault and inhibit torque. Calibrate real temperature and lag. |
| External feedback powered, board off | TMUX isolates MCU; floating ESD supply rail avoids a DC path into 3V3. 0–3.3 V signal contract still applies. |
| CAN cable before power / bus fault | TCAN bus protection and power-off behavior apply; standby held through reset. Verify actual network EMC and bus faults. |
| USB cable before power | CP2102 VBUS divider and same-rail UART eliminate the previous split-rail issue. Verify attach/detach and descriptors. |
| VCC, 3V3 or 5V_SYS fault | Driver UVLO/default pulls prevent intended switching; firmware brownout/reset inhibits torque. Backup braking is unavailable without its supplies. |

## Source basis

- [STSPIN32G4 DS13630 Rev 2](https://www.st.com/resource/en/datasheet/stspin32g4.pdf): exposed pins, bypass power, internal driver connections, VCC and protection. Local PDF retained. Exposed peripheral choices were checked against its pin-description table. [ST EVSPIN UM2850](https://www.st.com/resource/en/user_manual/um2850-getting-started-with-the-evspin32g4-evspin32g4nh-stmicroelectronics.pdf), current-sense protection example; [ST G4 LL comparator header](https://github.com/STMicroelectronics/stm32g4xx-hal-driver/blob/master/Inc/stm32g4xx_ll_comp.h), internal DAC choices.
- [TI CSD88599Q5DC SLPS597D](https://www.ti.com/lit/ds/symlink/csd88599q5dc.pdf), DMM0022A drawing 4222731/B; [CSD19531Q5A SLPS406B](https://www.ti.com/lit/ds/symlink/csd19531q5a.pdf), Q5A/DQJ copper and stencil; [TLV755P](https://www.ti.com/lit/ds/symlink/tlv755p.pdf), DYD0005A drawing 4228946/A.
- [LMR36510](https://www.ti.com/lit/ds/symlink/lmr36510.pdf), [TPS2121](https://www.ti.com/lit/ds/symlink/tps2121.pdf), [Wurth 74437349220](https://www.we-online.com/components/products/datasheet/74437349220.pdf), [Panasonic EEVFK1J681M](https://industrial.panasonic.com/tw/products/pt/aluminum-cap-smd/models/EEVFK1J681M), [BVR shunt](https://www.isabellenhuette.com/hubfs/143808517/files/Data%20sheets/BVR.pdf).
- [TLV3012B](https://www.ti.com/lit/ds/symlink/tlv3012.pdf), [UCC27517A](https://www.ti.com/lit/ds/symlink/ucc27517a.pdf), [B5100C](https://www.diodes.com/datasheet/download/B5100C.pdf), [TMUX1574](https://www.ti.com/lit/ds/symlink/tmux1574.pdf), [TPD3E001](https://www.ti.com/lit/ds/symlink/tpd3e001.pdf). Specify the **B** comparator for fail-safe inputs and power-on behavior.
- [CP2102N Rev 1.5](https://www.silabs.com/documents/public/data-sheets/cp2102n-datasheet.pdf), Fig. 2.3 and QFN20 pin table; [TCAN3413](https://www.ti.com/lit/ds/symlink/tcan3413.pdf). Sensor and connector sources remain in their schematic Datasheet fields.

## Remaining stage gates

There are no known unresolved schematic connectivity or assigned-footprint blockers in this release. Before fabrication: finish placement/routing, stack-up/current/thermal design, mechanical fit, DRC, printed footprint checks and fabricator review of via-in-pad/stencil details. Before raising power: verify regulation, fault shutdown, brake energy, switching overshoot, capacitor ripple and temperature. Raising the 25/40 Arms or 10S targets to guaranteed ratings can require another hardware revision.

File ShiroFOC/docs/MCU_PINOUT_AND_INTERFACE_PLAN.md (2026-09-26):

# ShiroFOC Rev A MCU Pinout and Interface Plan

Status: A0 layout-release allocation, checked against the STSPIN32G4 datasheet pin table. The native schematic and this table agree. STM32CubeMX has not been run; generate and verify the complete STM32G431VBx3 firmware configuration before motor commissioning. See [release review](DESIGN_REVIEW_REV_A.md) and [firmware contract](FIRMWARE_BRINGUP_CONTRACT.md).

## Design intent

- Preserve the STSPIN32G4 internal TIM1 gate-driver connections and all three integrated op-amp current-sense paths.
- Support onboard AS5047P ABI feedback, external incremental A/B/Z feedback, or external Hall U/V/W feedback.
- Use TIM4 channels 1, 2, and 3 for the three selected feedback inputs.
- Keep PB8/BOOT0 safe on a blank, assembled board by disabling the feedback mux in hardware during reset.
- Share SPI3 between the BMI323 IMU and AS5047P using independent chip-select signals; do not place a mux in the SPI path.
- Keep FDCAN1, a USB-to-UART service console, and SWD programming/debugging.
- Measure three phase-shunt currents, three MOSFET temperatures, and motor-bus voltage.
- Control a local external brake resistor through a dedicated low-side brake chopper.
- Report thermal state over CAN so system-level cooling can be controlled by the motherboard.

## Rev A external pin map
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

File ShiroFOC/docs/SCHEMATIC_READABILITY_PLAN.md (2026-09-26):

# ShiroFOC schematic readability review and redraw plan

Status: implemented as A1-Drawing on 2026-09-16. The assessment below records the original A0 problems. See [completed redraw review](SCHEMATIC_REDRAW_REVIEW.md) for the final sheet organization, verification and remaining scope.

## Assessment

The current schematic communicates a netlist rather than circuit operation. The previous readability sign-off was inadequate: absence of overlaps and a clean ERC are not sufficient to make a schematic understandable. Presentation readiness must be reopened; the existing electrical checks remain useful as the baseline for a redraw.

Inspection covered all 11 rendered pages and the native generator. There are **731 global labels**, **719 short wire segments**, and **zero junction objects**. The serializer unconditionally adds a global label to every connected component pin. All ten circuit pages use A2, although many contain only a small amount of circuitry. Scaling component positions apart further increases whitespace without improving topology.
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

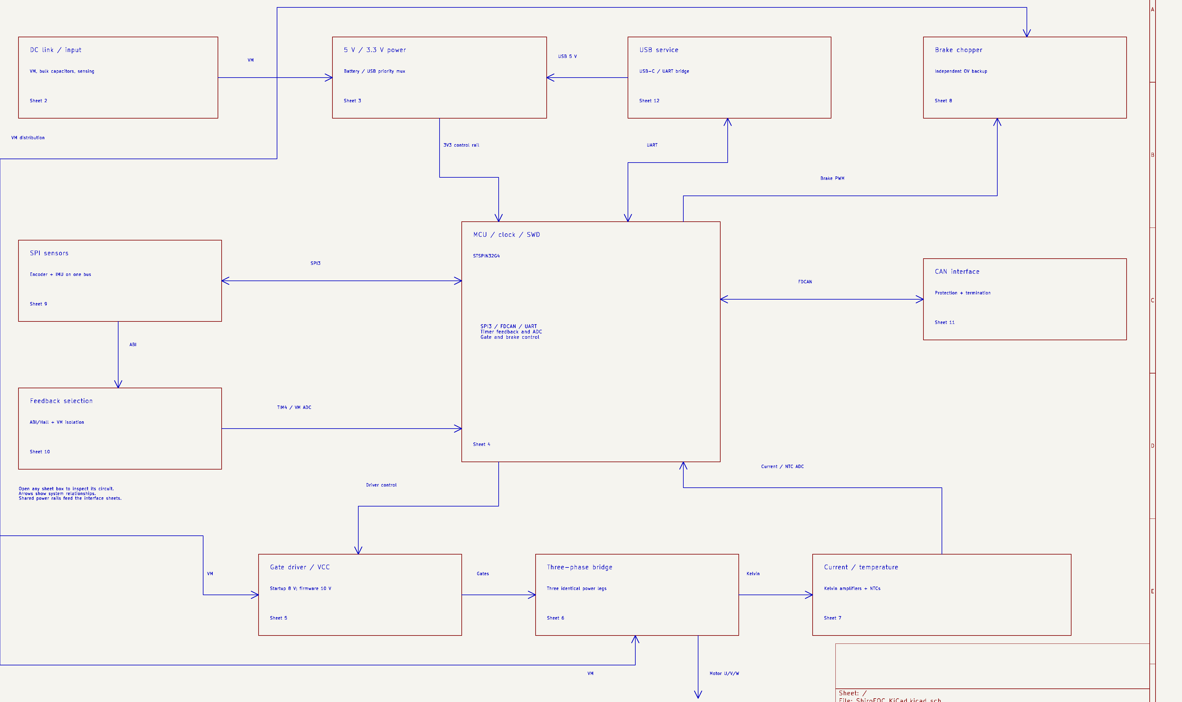
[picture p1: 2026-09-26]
ShiroFOC/presentation/.build/assets/overview.png

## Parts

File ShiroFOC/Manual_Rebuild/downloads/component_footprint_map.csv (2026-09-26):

References | Page / function | MPN | Value | Footprint | Footprint resolves | 3D model paths | CAD status | Assembly | Datasheet
H1 | / |  | M3 NPTH | MountingHole:MountingHole_3.2mm_M3 | True |  | Assigned; footprint file resolves. See review for qualification limits.
H2 | / |  | M3 NPTH | MountingHole:MountingHole_3.2mm_M3 | True |  | Assigned; footprint file resolves. See review for qualification limits.
H3 | / |  | M3 NPTH | MountingHole:MountingHole_3.2mm_M3 | True |  | Assigned; footprint file resolves. See review for qualification limits.
H4 | / |  | M3 NPTH | MountingHole:MountingHole_3.2mm_M3 | True |  | Assigned; footprint file resolves. See review for qualification limits.
C101 | /DC link / input/ | EEVFK1J681M | 680uF 63V | Manual:Panasonic_EEVFK_K16_18x16.5 | True | ${KICAD9_3DMODEL_DIR}/Capacitor_SMD.3dshapes/CP_Elec_18x17.5.step | Footprint present; generic model is approximate envelope. | FIT
C102 | /DC link / input/ | EEVFK1J681M | 680uF 63V | Manual:Panasonic_EEVFK_K16_18x16.5 | True | ${KICAD9_3DMODEL_DIR}/Capacitor_SMD.3dshapes/CP_Elec_18x17.5.step | Footprint present; generic model is approximate envelope. | FIT
C103 | /DC link / input/ | EEVFK1J681M | 680uF 63V | Manual:Panasonic_EEVFK_K16_18x16.5 | True | ${KICAD9_3DMODEL_DIR}/Capacitor_SMD.3dshapes/CP_Elec_18x17.5.step | Footprint present; generic model is approximate envelope. | FIT
C104 | /DC link / input/ |  | 4.7uF 100V X7R | Capacitor_SMD:C_1210_3225Metric | True | ${KICAD9_3DMODEL_DIR}/Capacitor_SMD.3dshapes/C_1210_3225Metric.step | Assigned; footprint file resolves. See review for qualification limits. | FIT
C105 | /DC link / input/ |  | 100nF 100V X7R | Capacitor_SMD:C_0805_2012Metric | True | ${KICAD9_3DMODEL_DIR}/Capacitor_SMD.3dshapes/C_0805_2012Metric.step | Assigned; footprint file resolves. See review for qualification limits. | FIT
C106 | /DC link / input/ |  | 10nF 100V C0G | Capacitor_SMD:C_0603_1608Metric | True | ${KICAD9_3DMODEL_DIR}/Capacitor_SMD.3dshapes/C_0603_1608Metric.step | Assigned; footprint file resolves. See review for qualification limits. | FIT
C107 | /DC link / input/ |  | RC DAMP C - TUNE | Capacitor_SMD:C_2220_5750Metric | True | ${KICAD9_3DMODEL_DIR}/Capacitor_SMD.3dshapes/C_2220_5750Metric.step | Assigned; footprint file resolves. See review for qualification limits. | DNP
C108 | /DC link / input/ |  | 10nF | Capacitor_SMD:C_0603_1608Metric | True | ${KICAD9_3DMODEL_DIR}/Capacitor_SMD.3dshapes/C_0603_1608Metric.step | Assigned; footprint file resolves. See review for qualification limits. | FIT
D101 | /DC link / input/ |  | VM TVS - SELECT AFTER TEST | Diode_SMD:D_SMC | True | ${KICAD9_3DMODEL_DIR}/Diode_SMD.3dshapes/D_SMC.step | Assigned; footprint file resolves. See review for qualification limits. | DNP
J101 | /DC link / input/ | XT60PW-M | AMASS XT60PW-M | Connector_AMASS:AMASS_XT60PW-M_1x02_P7.20mm_Horizontal | True | ${KICAD9_3DMODEL_DIR}/Connector_AMASS.3dshapes/AMASS_XT60PW-M_1x02_P7.20mm_Horizontal.step | Footprint present; model missing (wire model optional for J501). | FIT
R101 | /DC link / input/ |  | 470k 0.25W | Resistor_SMD:R_1206_3216Metric | True | ${KICAD9_3DMODEL_DIR}/Resistor_SMD.3dshapes/R_1206_3216Metric.step | Assigned; footprint file resolves. See review for qualification limits. | FIT
R102 | /DC link / input/ |  | RC DAMP R - TUNE | Resistor_SMD:R_2512_6332Metric | True | ${KICAD9_3DMODEL_DIR}/Resistor_SMD.3dshapes/R_2512_6332Metric.step | Assigned; footprint file resolves. See review for qualification limits. | DNP
R103 | /DC link / input/ |  | 270k 0.1% 100V | Resistor_SMD:R_1206_3216Metric | True | ${KICAD9_3DMODEL_DIR}/Resistor_SMD.3dshapes/R_1206_3216Metric.step | Assigned; footprint file resolves. See review for qualification limits. | FIT
R104 | /DC link / input/ |  | 270k 0.1% 100V | Resistor_SMD:R_1206_3216Metric | True | ${KICAD9_3DMODEL_DIR}/Resistor_SMD.3dshapes/R_1206_3216Metric.step | Assigned; footprint file resolves. See review for qualification limits. | FIT
R105 | /DC link / input/ |  | 27k 0.1% | Resistor_SMD:R_0603_1608Metric | True | ${KICAD9_3DMODEL_DIR}/Resistor_SMD.3dshapes/R_0603_1608Metric.step | Assigned; footprint file resolves. See review for qualification limits. | FIT
R106 | /DC link / input/ |  | 1k | Resistor_SMD:R_0603_1608Metric | True | ${KICAD9_3DMODEL_DIR}/Resistor_SMD.3dshapes/R_0603_1608Metric.step | Assigned; footprint file resolves. See review for qualification limits. | FIT
TP101 | /DC link / input/ | PCB feature | VM | TestPoint:TestPoint_Pad_D1.5mm | True |  | Assigned; footprint file resolves. See review for qualification limits. | FIT
TP102 | /DC link / input/ | PCB feature | GND | TestPoint:TestPoint_Pad_D1.5mm | True |  | Assigned; footprint file resolves. See review for qualification limits. | FIT
TP103 | /DC link / input/ | PCB feature | VBUS_SENSE | TestPoint:TestPoint_Pad_D1.5mm | True |  | Assigned; footprint file resolves. See review for qualification limits. | FIT
C201 | /5 V / 3.3 V power/ |  | 2.2uF 100V X7R | Capacitor_SMD:C_1210_3225Metric | True | ${KICAD9_3DMODEL_DIR}/Capacitor_SMD.3dshapes/C_1210_3225Metric.step | Assigned; footprint file resolves. See review for qualification limits. | FIT
C202 | /5 V / 3.3 V power/ |  | 220nF 100V X7R | Capacitor_SMD:C_0805_2012Metric | True | ${KICAD9_3DMODEL_DIR}/Capacitor_SMD.3dshapes/C_0805_2012Metric.step | Assigned; footprint file resolves. See review for qualification limits. | FIT
C203 | /5 V / 3.3 V power/ |  | 100nF | Capacitor_SMD:C_0603_1608Metric | True | ${KICAD9_3DMODEL_DIR}/Capacitor_SMD.3dshapes/C_0603_1608Metric.step | Assigned; footprint file resolves. See review for qualification limits. | FIT
C204 | /5 V / 3.3 V power/ |  | 1uF | Capacitor_SMD:C_0603_1608Metric | True | ${KICAD9_3DMODEL_DIR}/Capacitor_SMD.3dshapes/C_0603_1608Metric.step | Assigned; footprint file resolves. See review for qualification limits. | FIT
C205 | /5 V / 3.3 V power/ | C3225X7R1E226M250AB | 22uF 25V X7R | Capacitor_SMD:C_1210_3225Metric | True | ${KICAD9_3DMODEL_DIR}/Capacitor_SMD.3dshapes/C_1210_3225Metric.step | Exact TDK part/bias curves selected; standard 1210 footprint; generic STEP height may differ (allow2.7mm) | FIT | https://product.tdk.com/en/search/capacitor/ceramic/mlcc/info?part_no=C3225X7R1E226M250AB
C206 | /5 V / 3.3 V power/ | C3225X7R1E226M250AB | 22uF 25V X7R | Capacitor_SMD:C_1210_3225Metric | True | ${KICAD9_3DMODEL_DIR}/Capacitor_SMD.3dshapes/C_1210_3225Metric.step | Exact TDK part/bias curves selected; standard 1210 footprint; generic STEP height may differ (allow2.7mm) | FIT | https://product.tdk.com/en/search/capacitor/ceramic/mlcc/info?part_no=C3225X7R1E226M250AB
C209 | /5 V / 3.3 V power/ |  | 100nF | Capacitor_SMD:C_0603_1608Metric | True | ${KICAD9_3DMODEL_DIR}/Capacitor_SMD.3dshapes/C_0603_1608Metric.step | Assigned; footprint file resolves. See review for qualification limits. | FIT
C210 | /5 V / 3.3 V power/ |  | 22uF 10V X7R | Capacitor_SMD:C_1210_3225Metric | True | ${KICAD9_3DMODEL_DIR}/Capacitor_SMD.3dshapes/C_1210_3225Metric.step | Assigned; footprint file resolves. See review for qualification limits. | FIT
C211 | /5 V / 3.3 V power/ |  | 100nF | Capacitor_SMD:C_0603_1608Metric | True | ${KICAD9_3DMODEL_DIR}/Capacitor_SMD.3dshapes/C_0603_1608Metric.step | Assigned; footprint file resolves. See review for qualification limits. | FIT
C212 | /5 V / 3.3 V power/ |  | 2.2uF 10V X7R | Capacitor_SMD:C_0603_1608Metric | True | ${KICAD9_3DMODEL_DIR}/Capacitor_SMD.3dshapes/C_0603_1608Metric.step | Assigned; footprint file resolves. See review for qualification limits. | FIT
C213 | /5 V / 3.3 V power/ |  | 2.2uF 10V X7R | Capacitor_SMD:C_0603_1608Metric | True | ${KICAD9_3DMODEL_DIR}/Capacitor_SMD.3dshapes/C_0603_1608Metric.step | Assigned; footprint file resolves. See review for qualification limits. | FIT
C214 | /5 V / 3.3 V power/ | C3225X7R1E226M250AB | 22uF 25V X7R | Capacitor_SMD:C_1210_3225Metric | True | ${KICAD9_3DMODEL_DIR}/Capacitor_SMD.3dshapes/C_1210_3225Metric.step | Exact TDK part/bias curves selected; standard 1210 footprint; generic STEP height may differ (allow2.7mm) | FIT | https://product.tdk.com/en/search/capacitor/ceramic/mlcc/info?part_no=C3225X7R1E226M250AB
C215 | /5 V / 3.3 V power/ | C3225X7R1E226M250AB | 22uF 25V X7R | Capacitor_SMD:C_1210_3225Metric | True | ${KICAD9_3DMODEL_DIR}/Capacitor_SMD.3dshapes/C_1210_3225Metric.step | Exact TDK part/bias curves selected; standard 1210 footprint; generic STEP height may differ (allow2.7mm) | FIT | https://product.tdk.com/en/search/capacitor/ceramic/mlcc/info?part_no=C3225X7R1E226M250AB
C218 | /5 V / 3.3 V power/ | C3225X7R1C226M250AC | 22uF 16V X7R | Capacitor_SMD:C_1210_3225Metric | True | ${KICAD9_3DMODEL_DIR}/Capacitor_SMD.3dshapes/C_1210_3225Metric.step | Exact TDK part/bias curves selected; standard 1210 footprint; generic STEP height may differ (allow2.7mm) | FIT | https://product.tdk.com/en/search/capacitor/ceramic/mlcc/info?part_no=C3225X7R1C226M250AC
C219 | /5 V / 3.3 V power/ | C3225X7R1C226M250AC | 22uF 16V X7R | Capacitor_SMD:C_1210_3225Metric | True | ${KICAD9_3DMODEL_DIR}/Capacitor_SMD.3dshapes/C_1210_3225Metric.step | Exact TDK part/bias curves selected; standard 1210 footprint; generic STEP height may differ (allow2.7mm) | FIT | https://product.tdk.com/en/search/capacitor/ceramic/mlcc/info?part_no=C3225X7R1C226M250AC
L201 | /5 V / 3.3 V power/ | 74437349470 | 47uH / 1.9A | Manual:WE_LHMI_7050_74437349470 | True | ${KIPRJMOD}/libs/3dmodels/Download_STP_WE-LHMI-7050_rev1.stp | Assigned; footprint file resolves. See review for qualification limits. | FIT | https://www.we-online.com/components/products/datasheet/74437349470.pdf
R201 | /5 V / 3.3 V power/ |  | 100k 1% | Resistor_SMD:R_0603_1608Metric | True | ${KICAD9_3DMODEL_DIR}/Resistor_SMD.3dshapes/R_0603_1608Metric.step | Assigned; footprint file resolves. See review for qualification limits. | FIT
R202 | /5 V / 3.3 V power/ |  | 11.1k 1% | Resistor_SMD:R_0603_1608Metric | True | ${KICAD9_3DMODEL_DIR}/Resistor_SMD.3dshapes/R_0603_1608Metric.step | Assigned; footprint file resolves. See review for qualification limits. | FIT
R206 | /5 V / 3.3 V power/ |  | 15.0k 1% | Resistor_SMD:R_0603_1608Metric | True | ${KICAD9_3DMODEL_DIR}/Resistor_SMD.3dshapes/R_0603_1608Metric.step | Assigned; footprint file resolves. See review for qualification limits. | FIT
R207 | /5 V / 3.3 V power/ |  | 5.10k 1% | Resistor_SMD:R_0603_1608Metric | True | ${KICAD9_3DMODEL_DIR}/Resistor_SMD.3dshapes/R_0603_1608Metric.step | Assigned; footprint file resolves. See review for qualification limits. | FIT
R208 | /5 V / 3.3 V power/ |  | 10.0k 1% | Resistor_SMD:R_0603_1608Metric | True | ${KICAD9_3DMODEL_DIR}/Resistor_SMD.3dshapes/R_0603_1608Metric.step | Assigned; footprint file resolves. See review for qualification limits. | FIT
R209 | /5 V / 3.3 V power/ |  | 5.10k 1% | Resistor_SMD:R_0603_1608Metric | True | ${KICAD9_3DMODEL_DIR}/Resistor_SMD.3dshapes/R_0603_1608Metric.step | Assigned; footprint file resolves. See review for qualification limits. | FIT
R210 | /5 V / 3.3 V power/ | RC0603FR-0722KL | 22.0k 1% | Resistor_SMD:R_0603_1608Metric | True | ${KICAD9_3DMODEL_DIR}/Resistor_SMD.3dshapes/R_0603_1608Metric.step | Assigned; footprint file resolves. See review for qualification limits. | FIT
R211 | /5 V / 3.3 V power/ |  | 5.10k 1% | Resistor_SMD:R_0603_1608Metric | True | ${KICAD9_3DMODEL_DIR}/Resistor_SMD.3dshapes/R_0603_1608Metric.step | Assigned; footprint file resolves. See review for qualification limits. | FIT
R212 | /5 V / 3.3 V power/ | RC0603FR-0722KL | 22.0k 1% | Resistor_SMD:R_0603_1608Metric | True | ${KICAD9_3DMODEL_DIR}/Resistor_SMD.3dshapes/R_0603_1608Metric.step | Assigned; footprint file resolves. See review for qualification limits. | FIT
R213 | /5 V / 3.3 V power/ |  | 5.10k 1% | Resistor_SMD:R_0603_1608Metric | True | ${KICAD9_3DMODEL_DIR}/Resistor_SMD.3dshapes/R_0603_1608Metric.step | Assigned; footprint file resolves. See review for qualification limits. | FIT
R214 | /5 V / 3.3 V power/ |  | 80.6k 1% | Resistor_SMD:R_0603_1608Metric | True | ${KICAD9_3DMODEL_DIR}/Resistor_SMD.3dshapes/R_0603_1608Metric.step | Assigned; footprint file resolves. See review for qualification limits. | FIT
R215 | /5 V / 3.3 V power/ |  | 10k | Resistor_SMD:R_0603_1608Metric | True | ${KICAD9_3DMODEL_DIR}/Resistor_SMD.3dshapes/R_0603_1608Metric.step | Assigned; footprint file resolves. See review for qualification limits. | FIT
R216 | /5 V / 3.3 V power/ |  | 34.0k 0.1% | Resistor_SMD:R_0603_1608Metric | True | ${KICAD9_3DMODEL_DIR}/Resistor_SMD.3dshapes/R_0603_1608Metric.step | Assigned; footprint file resolves. See review for qualification limits. | FIT
R217 | /5 V / 3.3 V power/ |  | 6.49k 0.1% | Resistor_SMD:R_0603_1608Metric | True | ${KICAD9_3DMODEL_DIR}/Resistor_SMD.3dshapes/R_0603_1608Metric.step | Assigned; footprint file resolves. See review for qualification limits. | FIT
R218 | /5 V / 3.3 V power/ |  | 100k | Resistor_SMD:R_0603_1608Metric | True | ${KICAD9_3DMODEL_DIR}/Resistor_SMD.3dshapes/R_0603_1608Metric.step | Assigned; footprint file resolves. See review for qualification limits. | FIT
R219 | /5 V / 3.3 V power/ |  | 100k | Resistor_SMD:R_0603_1608Metric | True | ${KICAD9_3DMODEL_DIR}/Resistor_SMD.3dshapes/R_0603_1608Metric.step | Assigned; footprint file resolves. See review for qualification limits. | FIT
TP201 | /5 V / 3.3 V power/ | PCB feature | PWR_SOURCE_STATUS | TestPoint:TestPoint_Pad_D1.5mm | True |  | Assigned; footprint file resolves. See review for qualification limits. | FIT
TP1005 | /5 V / 3.3 V power/ | PCB feature | 5V_SYS | TestPoint:TestPoint_Pad_D1.0mm | True |  | Assigned; footprint file resolves. See review for qualification limits. | FIT
TP1006 | /5 V / 3.3 V power/ | PCB feature | 3V3 | TestPoint:TestPoint_Pad_D1.0mm | True |  | Assigned; footprint file resolves. See review for qualification limits. | FIT
U201 | /5 V / 3.3 V power/ | LMR36510FADDAR | LMR36510FADDAR | Manual:LMR36510_DDA | True | ${KIPRJMOD}/libs/3dmodels/DDA0008E.stp | Assigned; footprint file resolves. See review for qualification limits. | FIT | https://www.ti.com/lit/ds/symlink/lmr36510.pdf
U203 | /5 V / 3.3 V power/ | TPS2121RUXR | TPS2121RUXR | Manual:TPS2121_RUX | True | ${KIPRJMOD}/libs/3dmodels/RUX0012A.stp | Assigned; footprint file resolves. See review for qualification limits. | FIT | https://www.ti.com/lit/ds/symlink/tps2121.pdf
U204 | /5 V / 3.3 V power/ | TLV75533PDYDR | TLV75533PDYDR | Manual:TLV75533_DYD_GND | True | ${KIPRJMOD}/libs/3dmodels/DYD0005A.stp | Assigned; footprint file resolves. See review for qualification limits. | FIT | https://www.ti.com/lit/ds/symlink/tlv755p.pdf
U205 | /5 V / 3.3 V power/ | MPM3620AGQV-Z | MPM3620AGQV-Z | Manual:IC18_MPM3620AGQV-Z_MNP | True | ${KIPRJMOD}/libs/3dmodels/MPM3606AGQV.step | Assigned; family STEP; intentionally no NC/test pads 19/20. | FIT | https://www.monolithicpower.com/en/documentview/productdocument/index/version/2/document_type/Datasheet/lang/en/sku/MPM3620AGQV-Z/document_id/2100/
C301 | /MCU / clock / SWD/ |  | 100nF | Capacitor_SMD:C_0603_1608Metric | True | ${KICAD9_3DMODEL_DIR}/Capacitor_SMD.3dshapes/C_0603_1608Metric.step | Assigned; footprint file resolves. See review for qualification limits. | FIT
C302 | /MCU / clock / SWD/ |  | 10uF 10V | Capacitor_SMD:C_0805_2012Metric | True | ${KICAD9_3DMODEL_DIR}/Capacitor_SMD.3dshapes/C_0805_2012Metric.step | Assigned; footprint file resolves. See review for qualification limits. | FIT
C303 | /MCU / clock / SWD/ |  | 100nF | Capacitor_SMD:C_0603_1608Metric | True | ${KICAD9_3DMODEL_DIR}/Capacitor_SMD.3dshapes/C_0603_1608Metric.step | Assigned; footprint file resolves. See review for qualification limits. | FIT
C304 | /MCU / clock / SWD/ |  | 1uF | Capacitor_SMD:C_0603_1608Metric | True | ${KICAD9_3DMODEL_DIR}/Capacitor_SMD.3dshapes/C_0603_1608Metric.step | Assigned; footprint file resolves. See review for qualification limits. | FIT
C305 | /MCU / clock / SWD/ |  | 100nF | Capacitor_SMD:C_0603_1608Metric | True | ${KICAD9_3DMODEL_DIR}/Capacitor_SMD.3dshapes/C_0603_1608Metric.step | Assigned; footprint file resolves. See review for qualification limits. | FIT
C306 | /MCU / clock / SWD/ |  | 1uF | Capacitor_SMD:C_0603_1608Metric | True | ${KICAD9_3DMODEL_DIR}/Capacitor_SMD.3dshapes/C_0603_1608Metric.step | Assigned; footprint file resolves. See review for qualification limits. | FIT
C307 | /MCU / clock / SWD/ |  | 100nF | Capacitor_SMD:C_0603_1608Metric | True | ${KICAD9_3DMODEL_DIR}/Capacitor_SMD.3dshapes/C_0603_1608Metric.step | Assigned; footprint file resolves. See review for qualification limits. | FIT
C308 | /MCU / clock / SWD/ |  | 10pF C0G | Capacitor_SMD:C_0603_1608Metric | True | ${KICAD9_3DMODEL_DIR}/Capacitor_SMD.3dshapes/C_0603_1608Metric.step | Assigned; footprint file resolves. See review for qualification limits. | FIT
C309 | /MCU / clock / SWD/ |  | 10pF C0G | Capacitor_SMD:C_0603_1608Metric | True | ${KICAD9_3DMODEL_DIR}/Capacitor_SMD.3dshapes/C_0603_1608Metric.step | Assigned; footprint file resolves. See review for qualification limits. | FIT
C310 | /MCU / clock / SWD/ |  | 100nF | Capacitor_SMD:C_0603_1608Metric | True | ${KICAD9_3DMODEL_DIR}/Capacitor_SMD.3dshapes/C_0603_1608Metric.step | Assigned; footprint file resolves. See review for qualification limits. | FIT
D301 | /MCU / clock / SWD/ |  | RED | LED_SMD:LED_0603_1608Metric | True | ${KICAD9_3DMODEL_DIR}/LED_SMD.3dshapes/LED_0603_1608Metric.step | Assigned; footprint file resolves. See review for qualification limits. | FIT
J1001 | /MCU / clock / SWD/ | FTSH-105-01-L-DV-K | ARM Cortex SWD 10-pin | Manual:FTSH_105_01_L_DV_K | True | ${KIPRJMOD}/libs/3dmodels/CON10_2X5_DUK_FTSH_SAI.step | Assigned; footprint file resolves. See review for qualification limits. | FIT
R301 | /MCU / clock / SWD/ |  | 0R | Resistor_SMD:R_0603_1608Metric | True | ${KICAD9_3DMODEL_DIR}/Resistor_SMD.3dshapes/R_0603_1608Metric.step | Assigned; footprint file resolves. See review for qualification limits. | FIT
R302 | /MCU / clock / SWD/ |  | 0R | Resistor_SMD:R_0603_1608Metric | True | ${KICAD9_3DMODEL_DIR}/Resistor_SMD.3dshapes/R_0603_1608Metric.step | Assigned; footprint file resolves. See review for qualification limits. | FIT
R303 | /MCU / clock / SWD/ |  | 100k | Resistor_SMD:R_0603_1608Metric | True | ${KICAD9_3DMODEL_DIR}/Resistor_SMD.3dshapes/R_0603_1608Metric.step | Assigned; footprint file resolves. See review for qualification limits. | FIT
R304 | /MCU / clock / SWD/ |  | 1k | Resistor_SMD:R_0603_1608Metric | True | ${KICAD9_3DMODEL_DIR}/Resistor_SMD.3dshapes/R_0603_1608Metric.step | Assigned; footprint file resolves. See review for qualification limits. | FIT
SW301 | /MCU / clock / SWD/ |  | RESET | Button_Switch_SMD:SW_SPST_TL3305A | True | ${KICAD9_3DMODEL_DIR}/Button_Switch_SMD.3dshapes/SW_SPST_TL3305A.step | Assigned; footprint file resolves. See review for qualification limits. | FIT
TP303 | /MCU / clock / SWD/ | PCB feature | NRST | TestPoint:TestPoint_Pad_D1.5mm | True |  | Assigned; footprint file resolves. See review for qualification limits. | FIT
TP1008 | /MCU / clock / SWD/ | PCB feature | SWDIO | TestPoint:TestPoint_Pad_D1.0mm | True |  | Assigned; footprint file resolves. See review for qualification limits. | FIT
TP1009 | /MCU / clock / SWD/ | PCB feature | SWCLK | TestPoint:TestPoint_Pad_D1.0mm | True |  | Assigned; footprint file resolves. See review for qualification limits. | FIT
TP1021 | /MCU / clock / SWD/ | PCB feature | SPARE_GPIO_1 | TestPoint:TestPoint_Pad_D1.0mm | True |  | Assigned; footprint file resolves. See review for qualification limits. | FIT
TP1023 | /MCU / clock / SWD/ | PCB feature | EXT_SENSOR_FAULT_N | TestPoint:TestPoint_Pad_D1.0mm | True |  | Assigned; footprint file resolves. See review for qualification limits. | FIT
TP1024 | /MCU / clock / SWD/ | PCB feature | I2C2_SDA | TestPoint:TestPoint_Pad_D1.0mm | True |  | Assigned; footprint file resolves. See review for qualification limits. | FIT
U4 | /MCU / clock / SWD/ | STSPIN32G4 | STSPIN32G4 | Manual:QFN_IN32G4_STM | True | ${KIPRJMOD}/libs/3dmodels/QFN_IN32G4_STM.step | Assigned; footprint file resolves. See review for qualification limits. | FIT | ../DataSheets/STSPIN32G4.pdf
Y301 | /MCU / clock / SWD/ | CX3225FB24000C0FZZH1 | 24MHz 7pF | Crystal:Crystal_SMD_3225-4Pin_3.2x2.5mm | True | ${KICAD9_3DMODEL_DIR}/Crystal.3dshapes/Crystal_SMD_3225-4Pin_3.2x2.5mm.step | Exact Kyocera manufacturer lands verified; standard footprint and generic STEP; exact STEP optional | FIT | https://ele.kyocera.com/assets/products/crystal-device/specification/CX3225FB_7pF.pdf
C311 | /Gate driver / VCC/ |  | 220nF 100V | Capacitor_SMD:C_0805_2012Metric | True | ${KICAD9_3DMODEL_DIR}/Capacitor_SMD.3dshapes/C_0805_2012Metric.step | Assigned; footprint file resolves. See review for qualification limits. | FIT
C312 | /Gate driver / VCC/ |  | 10uF 25V X7R | Capacitor_SMD:C_1210_3225Metric | True | ${KICAD9_3DMODEL_DIR}/Capacitor_SMD.3dshapes/C_1210_3225Metric.step | Assigned; footprint file resolves. See review for qualification limits. | FIT
C313 | /Gate driver / VCC/ |  | 100nF 25V | Capacitor_SMD:C_0603_1608Metric | True | ${KICAD9_3DMODEL_DIR}/Capacitor_SMD.3dshapes/C_0603_1608Metric.step | Assigned; footprint file resolves. See review for qualification limits. | FIT
C314 | /Gate driver / VCC/ |  | 10nF | Capacitor_SMD:C_0603_1608Metric | True | ${KICAD9_3DMODEL_DIR}/Capacitor_SMD.3dshapes/C_0603_1608Metric.step | Assigned; footprint file resolves. See review for qualification limits. | FIT
R310 | /Gate driver / VCC/ |  | 100k | Resistor_SMD:R_0603_1608Metric | True | ${KICAD9_3DMODEL_DIR}/Resistor_SMD.3dshapes/R_0603_1608Metric.step | Assigned; footprint file resolves. See review for qualification limits. | FIT
R311 | /Gate driver / VCC/ |  | 10k | Resistor_SMD:R_0603_1608Metric | True | ${KICAD9_3DMODEL_DIR}/Resistor_SMD.3dshapes/R_0603_1608Metric.step | Assigned; footprint file resolves. See review for qualification limits. | FIT
R312 | /Gate driver / VCC/ |  | 1k | Resistor_SMD:R_0603_1608Metric | True | ${KICAD9_3DMODEL_DIR}/Resistor_SMD.3dshapes/R_0603_1608Metric.step | Assigned; footprint file resolves. See review for qualification limits. | FIT
TP301 | /Gate driver / VCC/ | PCB feature | VCC | TestPoint:TestPoint_Pad_D1.5mm | True |  | Assigned; footprint file resolves. See review for qualification limits. | FIT
TP302 | /Gate driver / VCC/ | PCB feature | SCREF | TestPoint:TestPoint_Pad_D1.5mm | True |  | Assigned; footprint file resolves. See review for qualification limits. | FIT
C1 | /Three-phase bridge/ | C1005X7S2A103K050BB | 10nF | Capacitor_SMD:C_0402_1005Metric | True | ${KICAD9_3DMODEL_DIR}/Capacitor_SMD.3dshapes/C_0402_1005Metric.step | Assigned; footprint file resolves. See review for qualification limits. |  | https://product.tdk.com/info/en/documents/chara_sheet/C1005X7S2A103K050BB.pdf
C2 | /Three-phase bridge/ | C3216X7R2A105K160AA | 1uF | Capacitor_SMD:C_1206_3216Metric | True | ${KICAD9_3DMODEL_DIR}/Capacitor_SMD.3dshapes/C_1206_3216Metric.step | Assigned; footprint file resolves. See review for qualification limits. |  | https://product.tdk.com/info/en/documents/chara_sheet/C3216X7R2A105K160AA.pdf
C3 | /Three-phase bridge/ | C3225X7S2A475K200AB | 4.7uF | Capacitor_SMD:C_1210_3225Metric | True | ${KICAD9_3DMODEL_DIR}/Capacitor_SMD.3dshapes/C_1210_3225Metric.step | Assigned; footprint file resolves. See review for qualification limits. |  | https://product.tdk.com/info/en/documents/chara_sheet/C3225X7S2A475K200AB.pdf
C4 | /Three-phase bridge/ | C1608X7R1H224K080AB | 220nF | Capacitor_SMD:C_0603_1608Metric | True | ${KICAD9_3DMODEL_DIR}/Capacitor_SMD.3dshapes/C_0603_1608Metric.step | Assigned; footprint file resolves. See review for qualification limits. |  | https://product.tdk.com/info/en/documents/chara_sheet/C1608X7R1H224K080AB.pdf
C5 | /Three-phase bridge/ | C1005X7S2A103K050BB | 10nF | Capacitor_SMD:C_0402_1005Metric | True | ${KICAD9_3DMODEL_DIR}/Capacitor_SMD.3dshapes/C_0402_1005Metric.step | Assigned; footprint file resolves. See review for qualification limits. |  | https://product.tdk.com/info/en/documents/chara_sheet/C1005X7S2A103K050BB.pdf
C6 | /Three-phase bridge/ | C3216X7R2A105K160AA | 1uF | Capacitor_SMD:C_1206_3216Metric | True | ${KICAD9_3DMODEL_DIR}/Capacitor_SMD.3dshapes/C_1206_3216Metric.step | Assigned; footprint file resolves. See review for qualification limits. |  | https://product.tdk.com/info/en/documents/chara_sheet/C3216X7R2A105K160AA.pdf
C7 | /Three-phase bridge/ | C3225X7S2A475K200AB | 4.7uF | Capacitor_SMD:C_1210_3225Metric | True | ${KICAD9_3DMODEL_DIR}/Capacitor_SMD.3dshapes/C_1210_3225Metric.step | Assigned; footprint file resolves. See review for qualification limits. |  | https://product.tdk.com/info/en/documents/chara_sheet/C3225X7S2A475K200AB.pdf
C8 | /Three-phase bridge/ | C1608X7R1H224K080AB | 220nF | Capacitor_SMD:C_0603_1608Metric | True | ${KICAD9_3DMODEL_DIR}/Capacitor_SMD.3dshapes/C_0603_1608Metric.step | Assigned; footprint file resolves. See review for qualification limits. |  | https://product.tdk.com/info/en/documents/chara_sheet/C1608X7R1H224K080AB.pdf
C9 | /Three-phase bridge/ | C1005X7S2A103K050BB | 10nF | Capacitor_SMD:C_0402_1005Metric | True | ${KICAD9_3DMODEL_DIR}/Capacitor_SMD.3dshapes/C_0402_1005Metric.step | Assigned; footprint file resolves. See review for qualification limits. |  | https://product.tdk.com/info/en/documents/chara_sheet/C1005X7S2A103K050BB.pdf
C10 | /Three-phase bridge/ | C3216X7R2A105K160AA | 1uF | Capacitor_SMD:C_1206_3216Metric | True | ${KICAD9_3DMODEL_DIR}/Capacitor_SMD.3dshapes/C_1206_3216Metric.step | Assigned; footprint file resolves. See review for qualification limits. |  | https://product.tdk.com/info/en/documents/chara_sheet/C3216X7R2A105K160AA.pdf
C11 | /Three-phase bridge/ | C3225X7S2A475K200AB | 4.7uF | Capacitor_SMD:C_1210_3225Metric | True | ${KICAD9_3DMODEL_DIR}/Capacitor_SMD.3dshapes/C_1210_3225Metric.step | Assigned; footprint file resolves. See review for qualification limits. |  | https://product.tdk.com/info/en/documents/chara_sheet/C3225X7S2A475K200AB.pdf
C12 | /Three-phase bridge/ | C1608X7R1H224K080AB | 220nF | Capacitor_SMD:C_0603_1608Metric | True | ${KICAD9_3DMODEL_DIR}/Capacitor_SMD.3dshapes/C_0603_1608Metric.step | Assigned; footprint file resolves. See review for qualification limits. |  | https://product.tdk.com/info/en/documents/chara_sheet/C1608X7R1H224K080AB.pdf
J1 | /Three-phase bridge/ | PCB feature | MOTOR U/V/W | Connector_Wire:SolderWire-6sqmm_1x03_P14mm_D3.5mm_OD7mm | True | ${KICAD9_3DMODEL_DIR}/Connector_Wire.3dshapes/SolderWire-6sqmm_1x03_P14mm_D3.5mm_OD7mm.step | Standard footprint selected and pad-net checked; see current review |  | ~
R1 | /Three-phase bridge/ | LR2512D-3W-0.5mR-1% | 0.5m 1% | Manual:R_Shunt_LR2512D_0m5_3W_Kelvin | True | ${KICAD9_3DMODEL_DIR}/Resistor_SMD.3dshapes/R_2512_6332Metric.step | Manufacturer main lands; custom horizontal PCB Kelvin stubs, net ties 1-2 and 3-4. Generic approximate body model. Validation: review/kelvin_shunt. |  | ${KIPRJMOD}/../DataSheets/LR2512D_C500733.pdf
R2 | /Three-phase bridge/ | RC0805FR-074R7L | 4R7 | Resistor_SMD:R_0805_2012Metric | True | ${KICAD9_3DMODEL_DIR}/Resistor_SMD.3dshapes/R_0805_2012Metric.step | Assigned; footprint file resolves. See review for qualification limits. |  | https://www.yageogroup.com/component-documentation/download/specsheet/RC0805FR-074R7L
R3 | /Three-phase bridge/ | LR2512D-3W-0.5mR-1% | 0.5m 1% | Manual:R_Shunt_LR2512D_0m5_3W_Kelvin | True | ${KICAD9_3DMODEL_DIR}/Resistor_SMD.3dshapes/R_2512_6332Metric.step | Manufacturer main lands; custom horizontal PCB Kelvin stubs, net ties 1-2 and 3-4. Generic approximate body model. Validation: review/kelvin_shunt. |  | ${KIPRJMOD}/../DataSheets/LR2512D_C500733.pdf
R4 | /Three-phase bridge/ | RC0805FR-074R7L | 4R7 | Resistor_SMD:R_0805_2012Metric | True | ${KICAD9_3DMODEL_DIR}/Resistor_SMD.3dshapes/R_0805_2012Metric.step | Assigned; footprint file resolves. See review for qualification limits. |  | https://www.yageogroup.com/component-documentation/download/specsheet/RC0805FR-074R7L
R5 | /Three-phase bridge/ | LR2512D-3W-0.5mR-1% | 0.5m 1% | Manual:R_Shunt_LR2512D_0m5_3W_Kelvin | True | ${KICAD9_3DMODEL_DIR}/Resistor_SMD.3dshapes/R_2512_6332Metric.step | Manufacturer main lands; custom horizontal PCB Kelvin stubs, net ties 1-2 and 3-4. Generic approximate body model. Validation: review/kelvin_shunt. |  | ${KIPRJMOD}/../DataSheets/LR2512D_C500733.pdf
R6 | /Three-phase bridge/ | RC0805FR-074R7L | 4R7 | Resistor_SMD:R_0805_2012Metric | True | ${KICAD9_3DMODEL_DIR}/Resistor_SMD.3dshapes/R_0805_2012Metric.step | Assigned; footprint file resolves. See review for qualification limits. |  | https://www.yageogroup.com/component-documentation/download/specsheet/RC0805FR-074R7L
U1 | /Three-phase bridge/ | CSD88599Q5DC | CSD88599Q5DC | Manual:DMM0022A | True | ${KIPRJMOD}/libs/3dmodels/DMM0022A.stp | TI pad mapping repaired; imported geometry and STEP retained; native PCB pad fixture passed |  | https://www.ti.com/lit/ds/symlink/csd88599q5dc.pdf
U2 | /Three-phase bridge/ | CSD88599Q5DC | CSD88599Q5DC | Manual:DMM0022A | True | ${KIPRJMOD}/libs/3dmodels/DMM0022A.stp | TI pad mapping repaired; imported geometry and STEP retained; native PCB pad fixture passed |  | https://www.ti.com/lit/ds/symlink/csd88599q5dc.pdf
U3 | /Three-phase bridge/ | CSD88599Q5DC | CSD88599Q5DC | Manual:DMM0022A | True | ${KIPRJMOD}/libs/3dmodels/DMM0022A.stp | TI pad mapping repaired; imported geometry and STEP retained; native PCB pad fixture passed |  | https://www.ti.com/lit/ds/symlink/csd88599q5dc.pdf
C414 | /Current / temperature/ | C1608C0G1H470J080AA | 47pF C0G | Capacitor_SMD:C_0603_1608Metric | True | ${KICAD9_3DMODEL_DIR}/Capacitor_SMD.3dshapes/C_0603_1608Metric.step | Assigned; footprint file resolves. See review for qualification limits. | DNP | https://product.tdk.com/en/system/files/dam/doc/product/capacitor/ceramic/mlcc/charasheet/c1608c0g1h470j080aa.pdf
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

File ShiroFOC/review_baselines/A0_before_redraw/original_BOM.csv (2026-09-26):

Reference | Value | Footprint | MPN | Assembly | Rating | Procurement | Datasheet | DNP
C101 | 680uF 63V | Capacitor_SMD:CP_Elec_18x17.5 | EEVFK1J681M | FIT | See Value; generic low-voltage passives: R >=0.1 W / 50 V, C >=16 V X7R unless specified
C102 | 680uF 63V | Capacitor_SMD:CP_Elec_18x17.5 | EEVFK1J681M | FIT | See Value; generic low-voltage passives: R >=0.1 W / 50 V, C >=16 V X7R unless specified
C103 | 680uF 63V | Capacitor_SMD:CP_Elec_18x17.5 | EEVFK1J681M | FIT | See Value; generic low-voltage passives: R >=0.1 W / 50 V, C >=16 V X7R unless specified
C104 | 4.7uF 100V X7R | Capacitor_SMD:C_1210_3225Metric |  | FIT | See Value; generic low-voltage passives: R >=0.1 W / 50 V, C >=16 V X7R unless specified | Select to specification: 4.7uF 100V X7R; C_1210_3225Metric
C105 | 100nF 100V X7R | Capacitor_SMD:C_0805_2012Metric |  | FIT | See Value; generic low-voltage passives: R >=0.1 W / 50 V, C >=16 V X7R unless specified | Select to specification: 100nF 100V X7R; C_0805_2012Metric
C106 | 10nF 100V C0G | Capacitor_SMD:C_0603_1608Metric |  | FIT | See Value; generic low-voltage passives: R >=0.1 W / 50 V, C >=16 V X7R unless specified | Select to specification: 10nF 100V C0G; C_0603_1608Metric
C107 | RC DAMP C - TUNE | Capacitor_SMD:C_2220_5750Metric |  | DNP | See Value; generic low-voltage passives: R >=0.1 W / 50 V, C >=16 V X7R unless specified | Select to specification: RC DAMP C - TUNE; C_2220_5750Metric |  | DNP
C108 | 10nF | Capacitor_SMD:C_0603_1608Metric |  | FIT | See Value; generic low-voltage passives: R >=0.1 W / 50 V, C >=16 V X7R unless specified | Select to specification: 10nF; C_0603_1608Metric
C201 | 2.2uF 100V X7R | Capacitor_SMD:C_1210_3225Metric |  | FIT | See Value; generic low-voltage passives: R >=0.1 W / 50 V, C >=16 V X7R unless specified | Select to specification: 2.2uF 100V X7R; C_1210_3225Metric
C202 | 220nF 100V X7R | Capacitor_SMD:C_0805_2012Metric |  | FIT | See Value; generic low-voltage passives: R >=0.1 W / 50 V, C >=16 V X7R unless specified | Select to specification: 220nF 100V X7R; C_0805_2012Metric
C203 | 100nF | Capacitor_SMD:C_0603_1608Metric |  | FIT | See Value; generic low-voltage passives: R >=0.1 W / 50 V, C >=16 V X7R unless specified | Select to specification: 100nF; C_0603_1608Metric
C204 | 1uF | Capacitor_SMD:C_0603_1608Metric |  | FIT | See Value; generic low-voltage passives: R >=0.1 W / 50 V, C >=16 V X7R unless specified | Select to specification: 1uF; C_0603_1608Metric
C205 | 22uF 10V X7R | Capacitor_SMD:C_1210_3225Metric |  | FIT | See Value; generic low-voltage passives: R >=0.1 W / 50 V, C >=16 V X7R unless specified | Select to specification: 22uF 10V X7R; C_1210_3225Metric
C206 | 22uF 10V X7R | Capacitor_SMD:C_1210_3225Metric |  | FIT | See Value; generic low-voltage passives: R >=0.1 W / 50 V, C >=16 V X7R unless specified | Select to specification: 22uF 10V X7R; C_1210_3225Metric
C207 | 4.7nF 2kV | Capacitor_SMD:C_1206_3216Metric |  | DNP | See Value; generic low-voltage passives: R >=0.1 W / 50 V, C >=16 V X7R unless specified | Select to specification: 4.7nF 2kV; C_1206_3216Metric |  | DNP
C208 | 1uF 10V | Capacitor_SMD:C_0603_1608Metric |  | FIT | See Value; generic low-voltage passives: R >=0.1 W / 50 V, C >=16 V X7R unless specified | Select to specification: 1uF 10V; C_0603_1608Metric
C209 | 100nF | Capacitor_SMD:C_0603_1608Metric |  | FIT | See Value; generic low-voltage passives: R >=0.1 W / 50 V, C >=16 V X7R unless specified | Select to specification: 100nF; C_0603_1608Metric
C210 | 22uF 10V X7R | Capacitor_SMD:C_1210_3225Metric |  | FIT | See Value; generic low-voltage passives: R >=0.1 W / 50 V, C >=16 V X7R unless specified | Select to specification: 22uF 10V X7R; C_1210_3225Metric
C211 | 100nF | Capacitor_SMD:C_0603_1608Metric |  | FIT | See Value; generic low-voltage passives: R >=0.1 W / 50 V, C >=16 V X7R unless specified | Select to specification: 100nF; C_0603_1608Metric
C212 | 2.2uF 10V X7R | Capacitor_SMD:C_0603_1608Metric |  | FIT | See Value; generic low-voltage passives: R >=0.1 W / 50 V, C >=16 V X7R unless specified | Select to specification: 2.2uF 10V X7R; C_0603_1608Metric
C213 | 2.2uF 10V X7R | Capacitor_SMD:C_0603_1608Metric |  | FIT | See Value; generic low-voltage passives: R >=0.1 W / 50 V, C >=16 V X7R unless specified | Select to specification: 2.2uF 10V X7R; C_0603_1608Metric
C301 | 100nF | Capacitor_SMD:C_0603_1608Metric |  | FIT | See Value; generic low-voltage passives: R >=0.1 W / 50 V, C >=16 V X7R unless specified | Select to specification: 100nF; C_0603_1608Metric
C302 | 10uF 10V | Capacitor_SMD:C_0805_2012Metric |  | FIT | See Value; generic low-voltage passives: R >=0.1 W / 50 V, C >=16 V X7R unless specified | Select to specification: 10uF 10V; C_0805_2012Metric
C303 | 100nF | Capacitor_SMD:C_0603_1608Metric |  | FIT | See Value; generic low-voltage passives: R >=0.1 W / 50 V, C >=16 V X7R unless specified | Select to specification: 100nF; C_0603_1608Metric
C304 | 1uF | Capacitor_SMD:C_0603_1608Metric |  | FIT | See Value; generic low-voltage passives: R >=0.1 W / 50 V, C >=16 V X7R unless specified | Select to specification: 1uF; C_0603_1608Metric
C305 | 100nF | Capacitor_SMD:C_0603_1608Metric |  | FIT | See Value; generic low-voltage passives: R >=0.1 W / 50 V, C >=16 V X7R unless specified | Select to specification: 100nF; C_0603_1608Metric
C306 | 1uF | Capacitor_SMD:C_0603_1608Metric |  | FIT | See Value; generic low-voltage passives: R >=0.1 W / 50 V, C >=16 V X7R unless specified | Select to specification: 1uF; C_0603_1608Metric
C307 | 100nF | Capacitor_SMD:C_0603_1608Metric |  | FIT | See Value; generic low-voltage passives: R >=0.1 W / 50 V, C >=16 V X7R unless specified | Select to specification: 100nF; C_0603_1608Metric
C308 | 10pF C0G | Capacitor_SMD:C_0603_1608Metric |  | FIT | See Value; generic low-voltage passives: R >=0.1 W / 50 V, C >=16 V X7R unless specified | Select to specification: 10pF C0G; C_0603_1608Metric
C309 | 10pF C0G | Capacitor_SMD:C_0603_1608Metric |  | FIT | See Value; generic low-voltage passives: R >=0.1 W / 50 V, C >=16 V X7R unless specified | Select to specification: 10pF C0G; C_0603_1608Metric
C310 | 100nF | Capacitor_SMD:C_0603_1608Metric |  | FIT | See Value; generic low-voltage passives: R >=0.1 W / 50 V, C >=16 V X7R unless specified | Select to specification: 100nF; C_0603_1608Metric
C311 | 220nF 100V | Capacitor_SMD:C_0805_2012Metric |  | FIT | See Value; generic low-voltage passives: R >=0.1 W / 50 V, C >=16 V X7R unless specified | Select to specification: 220nF 100V; C_0805_2012Metric
C312 | 10uF 25V X7R | Capacitor_SMD:C_1210_3225Metric |  | FIT | See Value; generic low-voltage passives: R >=0.1 W / 50 V, C >=16 V X7R unless specified | Select to specification: 10uF 25V X7R; C_1210_3225Metric
C313 | 100nF 25V | Capacitor_SMD:C_0603_1608Metric |  | FIT | See Value; generic low-voltage passives: R >=0.1 W / 50 V, C >=16 V X7R unless specified | Select to specification: 100nF 25V; C_0603_1608Metric
C314 | 10nF | Capacitor_SMD:C_0603_1608Metric |  | FIT | See Value; generic low-voltage passives: R >=0.1 W / 50 V, C >=16 V X7R unless specified | Select to specification: 10nF; C_0603_1608Metric
C411 | 100nF 25V | Capacitor_SMD:C_0603_1608Metric |  | FIT | See Value; generic low-voltage passives: R >=0.1 W / 50 V, C >=16 V X7R unless specified | Select to specification: 100nF 25V; C_0603_1608Metric
C412 | 1uF 100V X7R | Capacitor_SMD:C_1210_3225Metric |  | FIT | See Value; generic low-voltage passives: R >=0.1 W / 50 V, C >=16 V X7R unless specified | Select to specification: 1uF 100V X7R; C_1210_3225Metric
C413 | SNUBBER C TUNE | Capacitor_SMD:C_1210_3225Metric |  | DNP | See Value; generic low-voltage passives: R >=0.1 W / 50 V, C >=16 V X7R unless specified | Select to specification: SNUBBER C TUNE; C_1210_3225Metric |  | DNP
C414 | 47pF C0G | Capacitor_SMD:C_0603_1608Metric |  | DNP | See Value; generic low-voltage passives: R >=0.1 W / 50 V, C >=16 V X7R unless specified | Select to specification: 47pF C0G; C_0603_1608Metric |  | DNP
C415 | 10nF 100V X7S | Capacitor_SMD:C_0402_1005Metric |  | FIT | See Value; generic low-voltage passives: R >=0.1 W / 50 V, C >=16 V X7R unless specified | Select to specification: 10nF 100V X7S; C_0402_1005Metric
C421 | 100nF 25V | Capacitor_SMD:C_0603_1608Metric |  | FIT | See Value; generic low-voltage passives: R >=0.1 W / 50 V, C >=16 V X7R unless specified | Select to specification: 100nF 25V; C_0603_1608Metric
C422 | 1uF 100V X7R | Capacitor_SMD:C_1210_3225Metric |  | FIT | See Value; generic low-voltage passives: R >=0.1 W / 50 V, C >=16 V X7R unless specified | Select to specification: 1uF 100V X7R; C_1210_3225Metric
C423 | SNUBBER C TUNE | Capacitor_SMD:C_1210_3225Metric |  | DNP | See Value; generic low-voltage passives: R >=0.1 W / 50 V, C >=16 V X7R unless specified | Select to specification: SNUBBER C TUNE; C_1210_3225Metric |  | DNP
C424 | 47pF C0G | Capacitor_SMD:C_0603_1608Metric |  | DNP | See Value; generic low-voltage passives: R >=0.1 W / 50 V, C >=16 V X7R unless specified | Select to specification: 47pF C0G; C_0603_1608Metric |  | DNP
C425 | 10nF 100V X7S | Capacitor_SMD:C_0402_1005Metric |  | FIT | See Value; generic low-voltage passives: R >=0.1 W / 50 V, C >=16 V X7R unless specified | Select to specification: 10nF 100V X7S; C_0402_1005Metric
C431 | 100nF 25V | Capacitor_SMD:C_0603_1608Metric |  | FIT | See Value; generic low-voltage passives: R >=0.1 W / 50 V, C >=16 V X7R unless specified | Select to specification: 100nF 25V; C_0603_1608Metric
C432 | 1uF 100V X7R | Capacitor_SMD:C_1210_3225Metric |  | FIT | See Value; generic low-voltage passives: R >=0.1 W / 50 V, C >=16 V X7R unless specified | Select to specification: 1uF 100V X7R; C_1210_3225Metric
C433 | SNUBBER C TUNE | Capacitor_SMD:C_1210_3225Metric |  | DNP | See Value; generic low-voltage passives: R >=0.1 W / 50 V, C >=16 V X7R unless specified | Select to specification: SNUBBER C TUNE; C_1210_3225Metric |  | DNP
C434 | 47pF C0G | Capacitor_SMD:C_0603_1608Metric |  | DNP | See Value; generic low-voltage passives: R >=0.1 W / 50 V, C >=16 V X7R unless specified | Select to specification: 47pF C0G; C_0603_1608Metric |  | DNP
C435 | 10nF 100V X7S | Capacitor_SMD:C_0402_1005Metric |  | FIT | See Value; generic low-voltage passives: R >=0.1 W / 50 V, C >=16 V X7R unless specified | Select to specification: 10nF 100V X7S; C_0402_1005Metric
C501 | 1uF 25V | Capacitor_SMD:C_0603_1608Metric |  | FIT | See Value; generic low-voltage passives: R >=0.1 W / 50 V, C >=16 V X7R unless specified | Select to specification: 1uF 25V; C_0603_1608Metric
C502 | 100nF 25V | Capacitor_SMD:C_0603_1608Metric |  | FIT | See Value; generic low-voltage passives: R >=0.1 W / 50 V, C >=16 V X7R unless specified | Select to specification: 100nF 25V; C_0603_1608Metric
C503 | 100nF | Capacitor_SMD:C_0603_1608Metric |  | FIT | See Value; generic low-voltage passives: R >=0.1 W / 50 V, C >=16 V X7R unless specified | Select to specification: 100nF; C_0603_1608Metric
C504 | 1nF C0G | Capacitor_SMD:C_0603_1608Metric |  | FIT | See Value; generic low-voltage passives: R >=0.1 W / 50 V, C >=16 V X7R unless specified | Select to specification: 1nF C0G; C_0603_1608Metric
C601 | 100nF | Capacitor_SMD:C_0603_1608Metric |  | FIT | See Value; generic low-voltage passives: R >=0.1 W / 50 V, C >=16 V X7R unless specified | Select to specification: 100nF; C_0603_1608Metric
C602 | 1uF | Capacitor_SMD:C_0603_1608Metric |  | FIT | See Value; generic low-voltage passives: R >=0.1 W / 50 V, C >=16 V X7R unless specified | Select to specification: 1uF; C_0603_1608Metric
C603 | 100nF | Capacitor_SMD:C_0603_1608Metric |  | FIT | See Value; generic low-voltage passives: R >=0.1 W / 50 V, C >=16 V X7R unless specified | Select to specification: 100nF; C_0603_1608Metric
C604 | 100nF 50V | Capacitor_SMD:C_0603_1608Metric |  | FIT | See Value; generic low-voltage passives: R >=0.1 W / 50 V, C >=16 V X7R unless specified | Select to specification: 100nF 50V; C_0603_1608Metric
C701 | 100nF | Capacitor_SMD:C_0603_1608Metric |  | FIT | See Value; generic low-voltage passives: R >=0.1 W / 50 V, C >=16 V X7R unless specified | Select to specification: 100nF; C_0603_1608Metric
C702 | 100nF | Capacitor_SMD:C_0603_1608Metric |  | FIT | See Value; generic low-voltage passives: R >=0.1 W / 50 V, C >=16 V X7R unless specified | Select to specification: 100nF; C_0603_1608Metric
C711 | 10nF | Capacitor_SMD:C_0603_1608Metric |  | FIT | See Value; generic low-voltage passives: R >=0.1 W / 50 V, C >=16 V X7R unless specified | Select to specification: 10nF; C_0603_1608Metric
C712 | 10nF | Capacitor_SMD:C_0603_1608Metric |  | FIT | See Value; generic low-voltage passives: R >=0.1 W / 50 V, C >=16 V X7R unless specified | Select to specification: 10nF; C_0603_1608Metric
C713 | 10nF | Capacitor_SMD:C_0603_1608Metric |  | FIT | See Value; generic low-voltage passives: R >=0.1 W / 50 V, C >=16 V X7R unless specified | Select to specification: 10nF; C_0603_1608Metric
C801 | 100nF | Capacitor_SMD:C_0603_1608Metric |  | FIT | See Value; generic low-voltage passives: R >=0.1 W / 50 V, C >=16 V X7R unless specified | Select to specification: 100nF; C_0603_1608Metric
C802 | 1uF | Capacitor_SMD:C_0603_1608Metric |  | FIT | See Value; generic low-voltage passives: R >=0.1 W / 50 V, C >=16 V X7R unless specified | Select to specification: 1uF; C_0603_1608Metric
C901 | 4.7uF 10V | Capacitor_SMD:C_0603_1608Metric |  | FIT | See Value; generic low-voltage passives: R >=0.1 W / 50 V, C >=16 V X7R unless specified | Select to specification: 4.7uF 10V; C_0603_1608Metric
C902 | 100nF | Capacitor_SMD:C_0603_1608Metric |  | FIT | See Value; generic low-voltage passives: R >=0.1 W / 50 V, C >=16 V X7R unless specified | Select to specification: 100nF; C_0603_1608Metric
C903 | 4.7uF 10V | Capacitor_SMD:C_0603_1608Metric |  | FIT | See Value; generic low-voltage passives: R >=0.1 W / 50 V, C >=16 V X7R unless specified | Select to specification: 4.7uF 10V; C_0603_1608Metric
C904 | 100nF | Capacitor_SMD:C_0603_1608Metric |  | FIT | See Value; generic low-voltage passives: R >=0.1 W / 50 V, C >=16 V X7R unless specified | Select to specification: 100nF; C_0603_1608Metric
D101 | VM TVS - SELECT AFTER TEST | Diode_SMD:D_SMC |  | DNP | See Value; generic low-voltage passives: R >=0.1 W / 50 V, C >=16 V X7R unless specified | Select to specification: VM TVS - SELECT AFTER TEST; D_SMC |  | DNP
D301 | RED | LED_SMD:LED_0603_1608Metric |  | FIT | See Value; generic low-voltage passives: R >=0.1 W / 50 V, C >=16 V X7R unless specified | Select to specification: RED; LED_0603_1608Metric
D302 | STPS1H100A | Diode_SMD:D_SMA | STPS1H100A | FIT | See Value; generic low-voltage passives: R >=0.1 W / 50 V, C >=16 V X7R unless specified
D501 | BZT52C12 12V | Diode_SMD:D_SOD-123 | BZT52C12 | FIT | See Value; generic low-voltage passives: R >=0.1 W / 50 V, C >=16 V X7R unless specified
D502 | BAT54H | Diode_SMD:D_SOD-123F | BAT54H,115 | FIT | See Value; generic low-voltage passives: R >=0.1 W / 50 V, C >=16 V X7R unless specified
D503 | BAT54H | Diode_SMD:D_SOD-123F | BAT54H,115 | FIT | See Value; generic low-voltage passives: R >=0.1 W / 50 V, C >=16 V X7R unless specified
D504 | B5100C 100V 5A | Diode_SMD:D_SMC | B5100C-13-F | FIT | See Value; generic low-voltage passives: R >=0.1 W / 50 V, C >=16 V X7R unless specified
D601 | TPD3E001DRLR 3-line ESD | Package_TO_SOT_SMD:Texas_R-PDSO-N5_DRL-5 | TPD3E001DRLR | FIT | See Value; generic low-voltage passives: R >=0.1 W / 50 V, C >=16 V X7R unless specified |  | https://www.ti.com/lit/ds/symlink/tpd3e001.pdf
D801 | PESD2CANFD24V-T | Package_TO_SOT_SMD:SOT-23 | PESD2CANFD24V-T | FIT | See Value; generic low-voltage passives: R >=0.1 W / 50 V, C >=16 V X7R unless specified |  | https://assets.nexperia.com/documents/data-sheet/PESD2CANFD24V-T.pdf
J101 | AMASS XT60PW-M | Connector_AMASS:AMASS_XT60PW-M_1x02_P7.20mm_Horizontal | XT60PW-M | FIT | See Value; generic low-voltage passives: R >=0.1 W / 50 V, C >=16 V X7R unless specified
J201 | USB-C service | Connector_USB:USB_C_Receptacle_HRO_TYPE-C-31-M-12 | TYPE-C-31-M-12 | FIT | See Value; generic low-voltage passives: R >=0.1 W / 50 V, C >=16 V X7R unless specified
J401 | MOTOR U/V/W | Connector_Wire:SolderWire-6sqmm_1x03_P14mm_D3.5mm_OD7mm |  | FIT | See Value; generic low-voltage passives: R >=0.1 W / 50 V, C >=16 V X7R unless specified | Select to specification: MOTOR U/V/W; SolderWire-6sqmm_1x03_P14mm_D3.5mm_OD7mm
J501 | BRAKE RESISTOR | Connector_Wire:SolderWire-2sqmm_1x02_P7.8mm_D2mm_OD3.9mm |  | FIT | See Value; generic low-voltage passives: R >=0.1 W / 50 V, C >=16 V X7R unless specified | Select to specification: BRAKE RESISTOR; SolderWire-2sqmm_1x02_P7.8mm_D2mm_OD3.9mm
J601 | EXT ENCODER / HALL | Connector_JST:JST_GH_BM06B-GHS-TBT_1x06-1MP_P1.25mm_Vertical | BM06B-GHS-TBT | FIT | See Value; generic low-voltage passives: R >=0.1 W / 50 V, C >=16 V X7R unless specified
J801 | CAN 1 | Connector_JST:JST_GH_BM04B-GHS-TBT_1x04-1MP_P1.25mm_Vertical | BM04B-GHS-TBT | FIT | See Value; generic low-voltage passives: R >=0.1 W / 50 V, C >=16 V X7R unless specified
J802 | CAN 2 | Connector_JST:JST_GH_BM04B-GHS-TBT_1x04-1MP_P1.25mm_Vertical | BM04B-GHS-TBT | FIT | See Value; generic low-voltage passives: R >=0.1 W / 50 V, C >=16 V X7R unless specified
J1001 | ARM Cortex SWD 10-pin | Connector_PinHeader_1.27mm:PinHeader_2x05_P1.27mm_Vertical_SMD | FTSH-105-01-L-DV-K | FIT | See Value; generic low-voltage passives: R >=0.1 W / 50 V, C >=16 V X7R unless specified
JP801 | TERM ENABLE | Jumper:SolderJumper-2_P1.3mm_Open_Pad1.0x1.5mm |  | DNP | See Value; generic low-voltage passives: R >=0.1 W / 50 V, C >=16 V X7R unless specified | Select to specification: TERM ENABLE; SolderJumper-2_P1.3mm_Open_Pad1.0x1.5mm |  | DNP
L201 | 22uH / 2.75A | ShiroFOC_Footprints:WE_LHMI_7050_74437349220 | 74437349220 | FIT | See Value; generic low-voltage passives: R >=0.1 W / 50 V, C >=16 V X7R unless specified
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

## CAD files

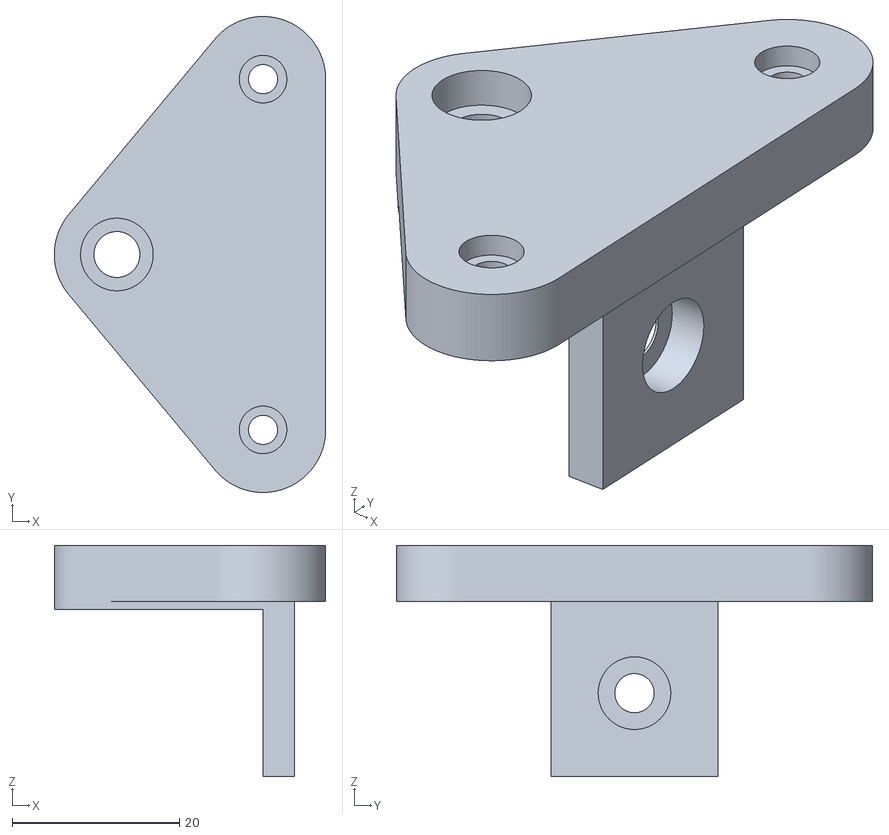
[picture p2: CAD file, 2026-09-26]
Plot-0/CAD/AxisMount2.stl
32.5 x 57.0 x 27.7

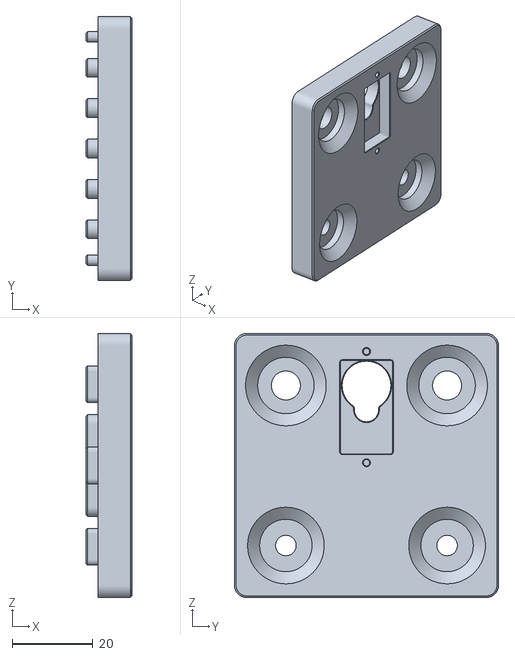
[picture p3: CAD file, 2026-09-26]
Plot-0/CAD/ServoMount.stl
11.5 x 65.5 x 65.5

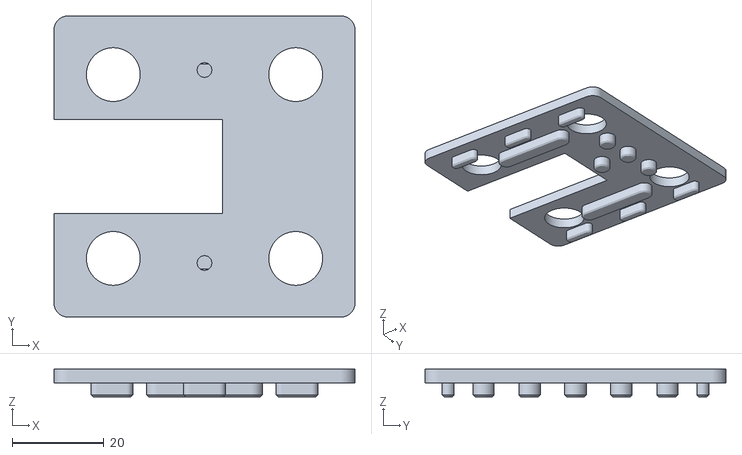
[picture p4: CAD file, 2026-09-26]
Plot-0/CAD/AxisMount1.stl
65.5 x 65.5 x 6.00

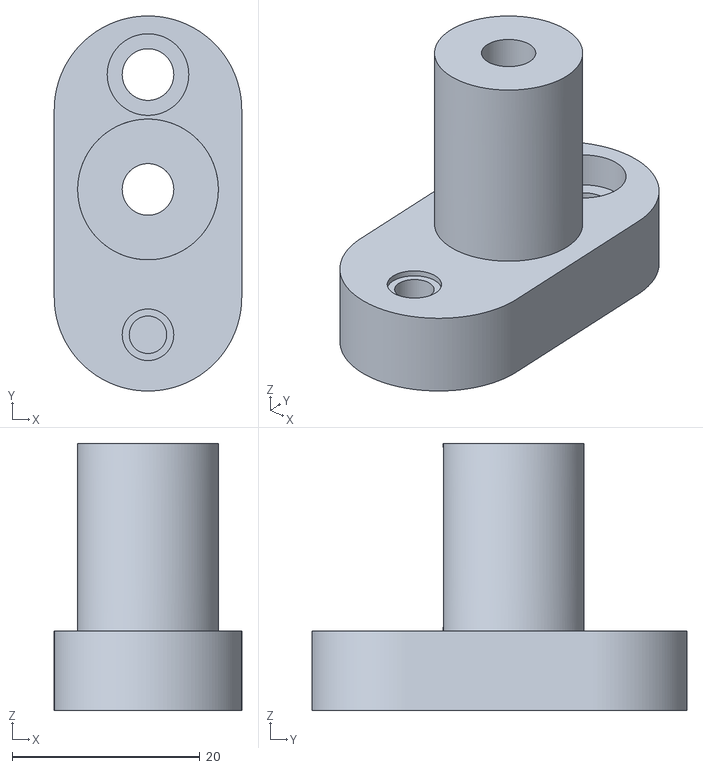
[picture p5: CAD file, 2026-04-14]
Plot-0/CAD/Tensioner1.stl
20.0 x 40.0 x 28.5

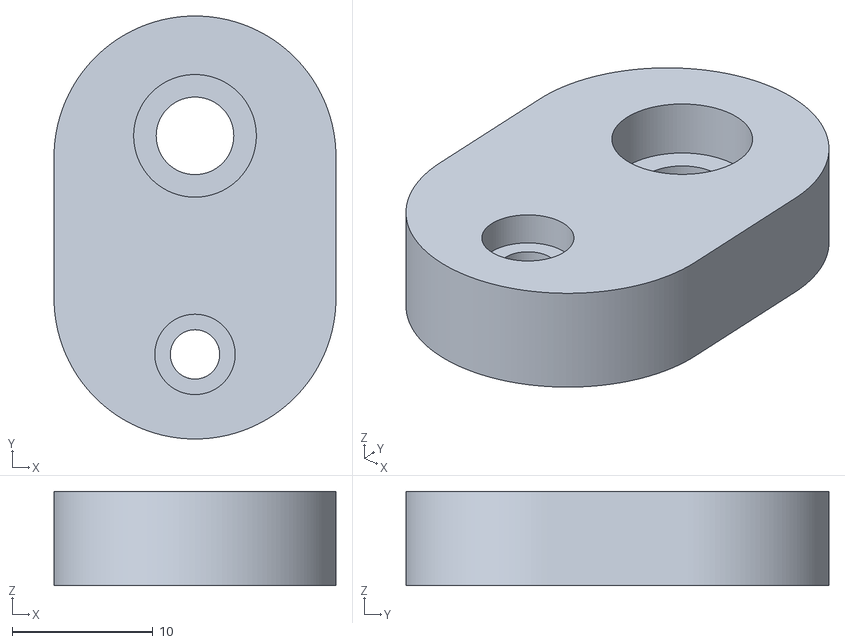
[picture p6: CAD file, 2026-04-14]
Plot-0/CAD/Tensioner2.stl
20.0 x 30.0 x 6.70

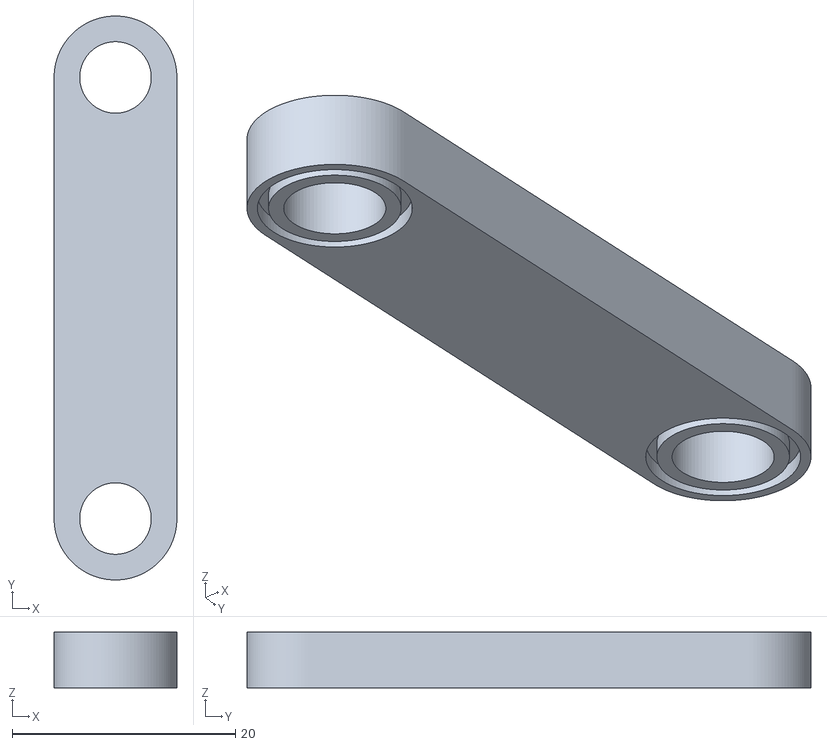
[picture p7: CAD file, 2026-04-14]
Plot-0/CAD/springPlate.stl
11.0 x 50.5 x 5.00

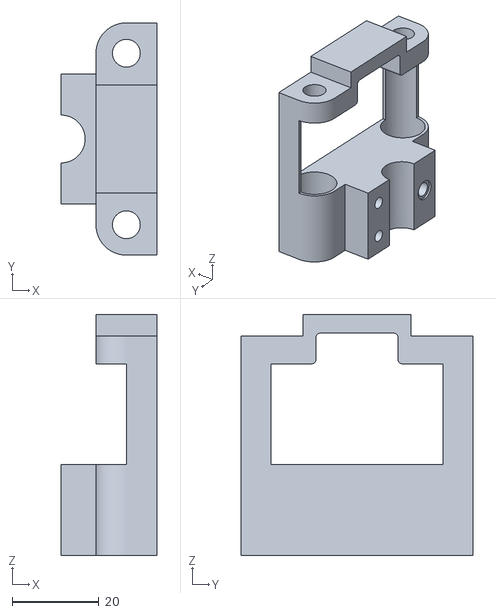
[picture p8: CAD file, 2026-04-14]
Plot-0/CAD/bearing_bracket.stl
22.0 x 53.5 x 55.5

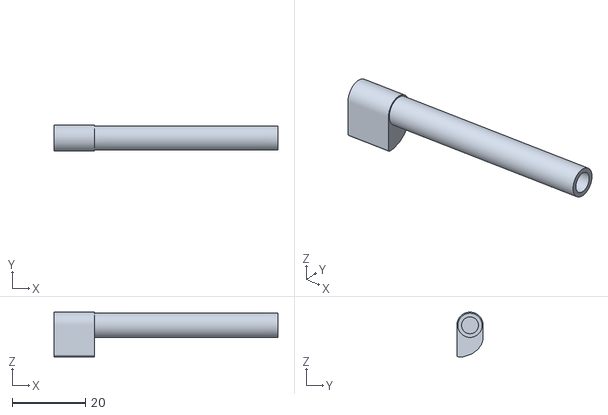
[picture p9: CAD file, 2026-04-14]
Plot-0/CAD/lobed.stl
61.0 x 7.20 x 12.2

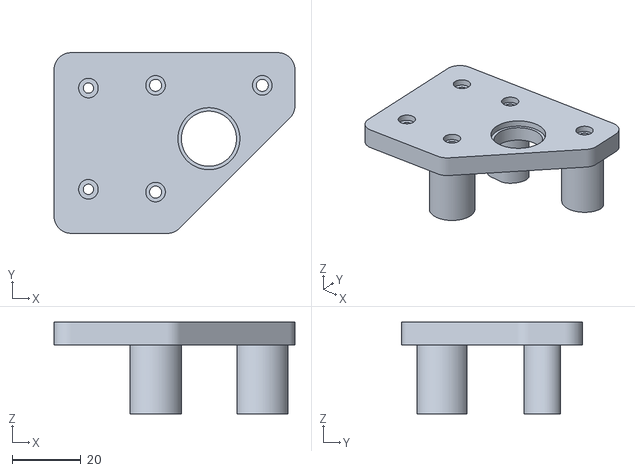
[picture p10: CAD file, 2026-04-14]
Plot-0/CAD/MotorMountA2.stl
70.0 x 52.5 x 26.7

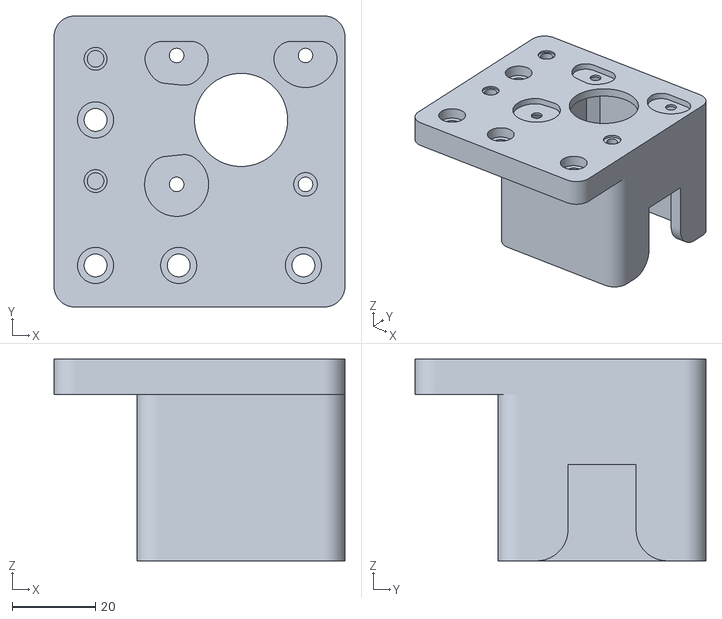
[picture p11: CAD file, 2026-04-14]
Plot-0/CAD/MotorMountA1.stl
70.0 x 70.0 x 48.5

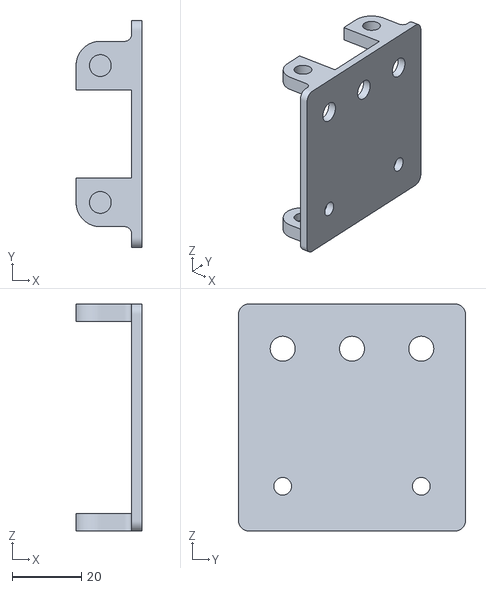
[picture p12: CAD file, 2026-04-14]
Plot-0/CAD/RodMount.stl
19.0 x 65.5 x 65.5

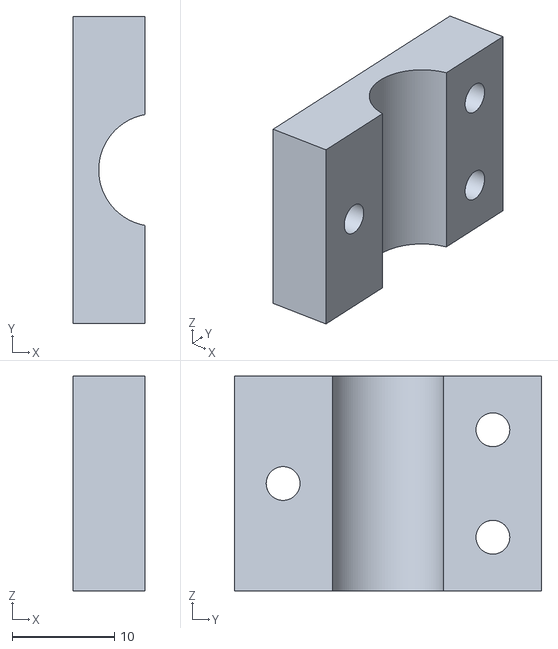
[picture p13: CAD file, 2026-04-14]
Plot-0/CAD/Clamp.stl
7.00 x 30.0 x 21.0

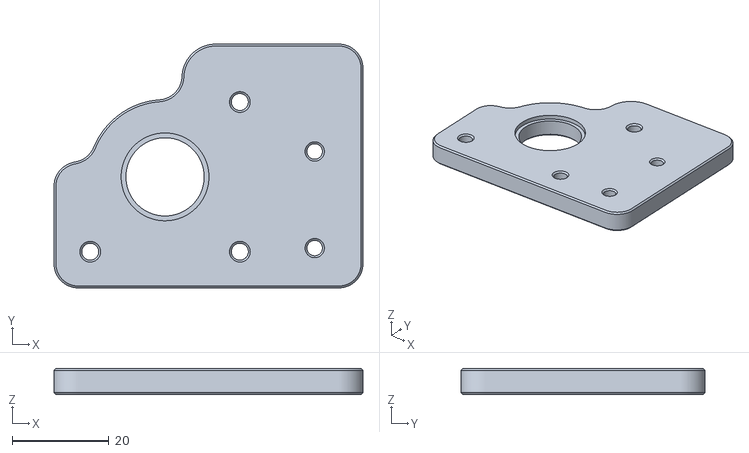
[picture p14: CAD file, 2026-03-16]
Plot-0/CAD/MotorMountA3.stl
64.0 x 50.5 x 5.45

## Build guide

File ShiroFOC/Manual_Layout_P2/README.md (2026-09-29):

# ShiroFOC P2 — manual layout starting point

Open **ShiroFOC_Manual.kicad_pro** in this folder, then its PCB. This is the new working revision. The prior P1 project and Manual_Rebuild files are preserved.

## What is carried forward

- P1's 80 × 80 mm rounded outline, four M3 mounting holes, bulk-capacitor row and parallel bridge/phase-output arrangement.
- Latest manual schematic and imported component libraries. U604 now uses standard SOT-23-6 with its generic model (TI DBV six-pin package, 0.95 mm pitch; standard KiCad lands are an IPC-style alternative to TI's example).
- Current footprint and net assignments, including the LR2512D Kelvin shunts. Source-reference changes such as U301 → U4 and Q401/Q402/Q403 → U1/U2/U3 are explicitly mapped.
- Four copper layers: 70 / 17.5 / 17.5 / 70 µm. The copied dielectric dimensions are provisional; they are not a confirmed fabrication stack or an impedance calculation.

This is **rough placement, intentionally unrouted**. Component shifts clear gross overlaps, not optimize every pin-local loop. Final placement, copper planes, routing, silkscreen and fabrication checks are the user's next steps. A guide box is not a copper zone or enforced keepout.

## Guide layers

| Layer | Content |
|---|---|
| Dwgs.User | Mechanical screw envelopes and routing reminders |
| User.1 | Bulk capacitors, three power cells and brake-stage regions |
| User.2 | Auxiliary supply, USB and external-interface regions |
| User.3 | MCU/analog area, centred underside encoder and sense-route direction hints |
| F.Fab / B.Fab | Component references and body outlines |

Hide the guide layers when they obstruct routing. Nothing on them is electrical copper.

## Placement and routing checklist

1. **Mechanics first:** retain the encoder centre on the back at (140,140) mm. The magnet is outside that face; no top-side central magnet void is required. Keep the MCU offset from the encoder to preserve space for underside decoupling. Check connector mating clearance and corner screw/washer envelopes; the circles show an 8 mm hardware envelope.
2. **Three repeated phase cells:** U1/U2/U3 line up with J1's U/V/W holes. Keep each VM ceramic → MOSFET pair → low-side shunt → ceramic ground loop short and broad. Respect the actual schematic: the three sets of local VM bypass capacitors return to GND. Do not copy older notes that put a capacitor above the shunt.
3. **Shunts:** active phase U/V/W shunts are R3/R1/R5 respectively, on the back near the power cells. Pads1/4 carry current; pads2/3 are the Kelvin pickup stubs. Route from the stubs as a close pair, away from phase/gate/brake switching nodes. Keep power pours from swallowing the stubs. Short direct force paths and multiple correctly sized vias are needed for backside shunts; there is no fixed amps-per-via guarantee.
4. **Gate drive:** finish placement around the actual U4 gate-driver pins before routing. Put R2/R4/R6 near the relevant GH gate pads. Pair the high-side drive with its source/phase return and low-side drive with its driver return. Bootstrap capacitors C4/C8/C12 are shown on the gate-driver sheet, between BOOTSTRAP1/2/3 and HS_RETURN_U/V/W. Place them at the driver pins. Route HS_RETURN directly to the corresponding MOSFET SH pad alongside the high-side gate trace; PHASE_U/V/W are separate high-current routes to the motor.
5. **Quiet measurement:** R417/R418/R419 and corresponding V/W networks, bias resistors and optional feedback capacitors belong close to their U4 amplifier pins. Use the underside of the MCU where useful, keeping clear of the encoder and hot power copper. Place VREF/VDDA filters and bypass capacitors close to their pins. Do not run main DC or brake return current through this area.
6. **Ground:** create substantially continuous GND planes on In1.Cu and In2.Cu. They provide signal return paths, not the sole motor-current conductor. Use broad outer-layer VM/GND paths for power. Stitch local decoupling grounds and signal layer transitions to the planes. Check both inner layers for accidental slots caused by via fields. A VM thermal via must not touch GND; likewise the source above each shunt is not GND.
7. **Brake:** keep the external resistor connector and chopper loop at the edge, away from the encoder. Finish Q501/U501 placement and gate loop before signal routing. Keep BRK_SW copper compact and sense the bus from a quieter pickup.
8. **Supplies:** current topology is VM → LMR36510/U201 + L201 → 10V → MPM3620A/U205 → 5V mux → 3V3 LDO. U4 uses external VCC; there is no L301 internal-switcher inductor. Finish capacitor placement at U201 and U205 first, then keep feedback resistors away from switching copper. U205's embedded footprint keepout remains present.
9. **Interfaces:** AS5047 uses dedicated SPI; BMI323 uses I2C. Keep both over continuous ground. Place external Hall protection/buffer and U604 sensor-power protector near J601; place their decouplers at their pins. CAN protection belongs at the connectors, with JP801 termination access. USB D+/D− should be short and paired; determine 90Ω geometry from a real stack before treating the saved width/gap as final.
10. **Comparison part:** R7 is the disconnected BVR4026 parked outside the outline. Compare it to the small shunts and then remove it before production exports. DNP/excluded-from-BOM does not remove its copper/paste from Gerbers.

## Saved routing presets

- Global copper clearance / minimum track width: 0.15 mm.
- Default logic: 0.25 mm track, 0.20 mm clearance.
- Analog: 0.20 mm track/clearance. Gate: 0.40 mm initial width. Logic power: 0.50 mm initial width.
- Power class: 0.50 mm clearance target; its 2 mm track width is a router convenience, **not a 25 A current-rating calculation**. Use purpose-sized copper.
- Through vias: 0.60 / 0.30 mm default; 0.45 / 0.20 mm compact. No blind/buried or microvia plan.
- Copper-to-edge: 0.50 mm. Drill spacing: 0.20 mm base; 0.45 mm for pairs involving component pads, with a retained explicit U901 thermal-via exception.
- Silkscreen: 1.0 mm minimum text / 0.15 mm stroke / 0.20 mm clearance. Imported library reference styling is not final production silkscreen.

See `review/` for the native ERC, unrouted-board DRC, footprint/pad-net validation and migration manifest. Those checks establish a usable starting project, not a finished-board release. Remaining fast-overcurrent-trip, thermal and shunt reflow-profile questions carry forward from the manual schematic review and firmware requirements.

## Known starting-state flags

See [open items](review/OPEN_ITEMS.md): U204's imported land pattern has 0.10 mm copper gaps, U901 has 0.15 mm thermal-via hole webs, and U205 has two NC/test symbol pins without footprint pads. These are recorded rather than hidden by relaxed rules. The board is ready for manual placement/routing work, not fabrication.

## Optional brake NTC — 27 September 2026

J502 is the new **bottom-side, left-edge** JST GH two-pin connector: **1 = NTC, 2 = GND**. Use an electrically insulated 10 kΩ-at-25°C probe on the external brake resistor; configure its actual temperature curve and rating. R511 is the 10 kΩ pull-up. R512/C505/D505 form the series filter and rail clamps beside U4 on the back. Keep the unfiltered probe net away from switching copper; route its dedicated ground back to the quiet ground plane, not through the brake-current return. No new routing has been added.

PC2 / U4 pad 11 is now `NTC_BRAKE` / ADC12_IN8. The status LED moved to PC15 / pad 5 with R304 = 2.2 kΩ; TP1021 is now labelled `STATUS_LED_N`. Existing footprint placement is preserved. Use the updated [firmware requirements](../requirements/FIRMWARE_REQUIREMENTS.md); old firmware that drives PC2 as an LED output is incompatible.

See [addition notes and checks](review/brake_ntc/README.md). `review/brake_ntc/before.zip` preserves the project files from before this addition. The older Manual_Rebuild project remains unchanged.

## Bootstrap return correction — 27 September 2026

The latest saved user placement is retained. C4/C8/C12 now appear on the gate-driver schematic sheet, connected between each BOOTSTRAP pin and its OUTx/SH return. `HS_RETURN_U/V/W` belong to the Gate class; `PHASE_U/V/W` belong to the Power class. Keep these PCB routes separate: they join inside the dual-MOSFET package. Capacitor values and footprints are unchanged.

The five NTC components also have corrected hierarchy paths and restored references J502/R511/R512/C505/D505. See [current verification](review/bootstrap_return/README.md).

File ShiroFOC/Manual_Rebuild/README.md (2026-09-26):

# Manual schematic review

**BVR comparison option:** R7 is a disconnected, DNP BVR-Z-R0005-1.0 with its BVR4026 footprint, excluded from the BOM but available for PCB placement comparison. Keep it off-board and remove before production exports. R1/R3/R5 remain the active LR2512D shunts.

**Shunt update:** [LR2512D two-terminal shunts with four PCB Kelvin connections](review/kelvin_shunt/README.md), applied to R1/R3/R5. This supersedes the historical BVR selection below. Generic 3D models accepted; no exact STEP downloads required.

**Current pre-layout status:** [Protected external sensor supply added](review/sensor_supply_protection/README.md): zero ERC violations,254 components; U604 footprint/3D deferred to final CAD pass. R3 coarse motor-current-trip validation remains for firmware/bench work. Complete other circuit decisions, then CAD association, then PCB layout.

## Cascaded power revision — 26 September 2026

The manual schematic now uses VM → 10 V (LMR36510) → 5 V (MPM3620A integrated-inductor module) → existing USB mux / 3.3 V LDO. STSPIN uses external VCC with SW tied to VM. See [change review](review/cascaded_power/REVIEW.md) and [updated supply drawings](review/cascaded_power/Power_Revision.pdf). The bridge and PCB are unchanged. U205 now uses the downloaded footprint with corrected keepout and the aligned supplier family STEP. Exact capacitor DC-bias qualification remains open. ERC remains at the same 16 pre-existing findings.

Open [ShiroFOC_Manual.kicad_pro](ShiroFOC_Manual.kicad_pro). This project now contains the complete P1 reference schematic **with your manually rebuilt MOSFET bridge retained**. Review and simplify this copy page by page.

## Start here

- **[Firmware requirements](../requirements/FIRMWARE_REQUIREMENTS.md):** current startup, BOOT0 option bytes, persistent calibration, sensing, faults and brake-chopper contract.

- [Footprint / STEP download checklist](downloads/FOOTPRINT_CAD_CHECKLIST.md): exact part numbers, component references, package distinctions and priorities.
- Put downloaded bundles in **[downloads/incoming/](downloads/incoming/)**.
- [Component-to-footprint catalogue](downloads/component_footprint_map.csv): all 253 components and current associations.
- [Import validation](review/import_validation.json): checks, remaining library issues and preserved-file evidence summary.

## Pages

| Page | Section |
|---|---|
| 1 | Functional overview and four M3 clearance holes |
| 2 | Battery / DC link |
| 3 | Auxiliary 5 V / 3.3 V power and source selection |
| 4 | STSPIN MCU, MCU supplies, clock, reset and SWD |
| 5 | STSPIN gate driver and VCC converter |
| 6 | **Your retained three-phase bridge** |
| 7 | Three current-sensing amplifiers and phase thermistors |
| 8 | Brake chopper |
| 9 | Dedicated encoder SPI3 and IMU I2C2 |
| 10 | Buffered external Hall / ABI and reset isolation |
| 11 | CAN |
| 12 | USB service |

## STSPIN and library organisation

U4 is one physical STSPIN32G4 using `Manual:STSPIN32G4_Functional`. Its copied reference symbol uses these units: A = MCU; B = MCU supplies; C = gate driver / VCC; D/E/F = current-sensing op-amps. All six retain your imported **`Manual:QFN_IN32G4_STM`** footprint and its existing STEP association. The downloaded original symbol remains in the library for reference.

Your MOSFETs U1/U2/U3 retain **`Manual:DMM0022A`**. Imported footprint files and STEP files were not changed. Custom schematic symbols are consolidated in the single `libs/Manual.kicad_sym` library. Footprints belong in `libs/Manual.pretty/`; models belong in `libs/3dmodels/`.

The **25 September CAD pass** checked 17 incoming ZIPs, updated 16 component associations, and linked 12 downloaded STEP models. TLV755 thermal-pad numbering and Panasonic bulk-capacitor lands were corrected. Standard geometry was retained where downloaded exports were incompatible. See the existing download checklist for the exact decisions, three missing purchased-part STEP models, approximate capacitor model and provisional crystal assignment.

## What was copied and preserved

Source: `../ShiroFOC_KiCad_P1/`. Ten functional sheets and the overview were copied, including optional/DNP circuitry and mounting holes. Source U301 becomes U4. Copied BOOT1/2/3 net names become BOOTSTRAP1/2/3 to match your retained bridge. The bridge's circuit, references, values and file content are unchanged.

The existing manual PCB was left untouched and **has not been synchronized** with the copied schematic. The original reference project was not modified. No extra component removals were made; you will choose those during your page-by-page review.

## Checks and remaining work

- Exported netlist matches the copied source circuitry, values, MPNs and assembly properties, excluding the intentionally substituted bridge.
- Retained bridge connectivity and file hash match the pre-copy state. Bootstrap and Kelvin interfaces connect to the copied driver/sensing sheets.
- U4 exports as one component; all 65 pins are represented and match the imported footprint pad-number set.
- Twelve pages export and render; modified overview, driver and sensing sheets were inspected at full size.
- ERC reports **16 findings**: 4 existing symbol/library mismatches, 5 existing bridge pin-type conflicts, and 7 power-drive declarations around the retained bridge/bootstrap interface. No ERC exclusions or suppressions were added. This is a review baseline, not a fabrication release.
- The retained MOSFET symbol uses literal pin ranges `[3-11]` / `[12-20]` that do not match individually numbered footprint pads. Additional footprint pads also need mapping. Resolve this before PCB synchronization; no repeat download is needed.
- R1/R3/R5 are now BVR-Z-R0005-1.0, 0.5 mΩ shunts; bridge passive values and footprints have been assigned. Only J1, U603 and JP601 currently have blank footprints. See the fresh checklist for exact actions.
- Purchased-part STEP files still missing: J101 (XT60PW-M), J201 (HRO USB-C), R1/R3/R5 (BVR shunt), U901 (CP2102N QFN20). J501 is a wire feature with an optional missing model. The capacitor STEP is approximate and the exact crystal package drawing still needs verification; see `downloads/FOOTPRINT_CAD_CHECKLIST.md`.

## Backups

Before the copy: `../backups/manual_before_reference_merge_2026-09-24_220041.zip`.

Before CAD association: `../backups/manual_before_cad_association_2026-09-25_100127.zip`. Validation: `review/cad_import_validation.json`.

Earlier manual stages remain in the existing `../backups/` archives. Existing generation scripts for the reference project do not target this manual folder.

## Downloaded CAD organization

Keep original bundles in `downloads/incoming/`. After checking pad numbers and package geometry, copy footprints into `libs/Manual.pretty/`, models into `libs/3dmodels/`, and assign `Manual:<footprint>` to the relevant symbol(s). Use `${KIPRJMOD}/libs/3dmodels/<model>.step` for model paths. Keep the functional schematic symbol; its appearance is independent of the footprint. Check model alignment in the 3D preview.

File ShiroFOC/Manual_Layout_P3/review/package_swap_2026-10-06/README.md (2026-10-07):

# CAN and ESD package substitutions — 2026-10-06

Project: Manual_Layout_P3. User-requested substitutions applied to schematic instances, embedded symbols, project symbol library, PCB footprints, and MPN/manufacturer fields.

| Reference | Old part | Replacement | Package |
|---|---|---|---|
| U801 | TCAN3413DR | TCAN3413DRBR | DRB VSON-8, 3 × 3 mm, 1.65 × 2.4 mm exposed pad |
| D601 | TPD3E001DRLR | TPD3E001DRYR | DRY USON-6, 1 × 1.45 mm |

## Pin mapping and layout

Verified against TI datasheets: https://www.ti.com/lit/ds/symlink/tcan3413.pdf and https://www.ti.com/lit/ds/symlink/tpd3e001.pdf.

- U801 pins 1–8 retain their nets. Exposed pad 9 is GND in the schematic and PCB, connected locally to pin 2. The standard footprint without built-in thermal vias was selected because opposite-side components occupy this area. Its final ground-plane via arrangement remains part of the ongoing board routing.
- D601 IO pins 1/2/4 and GND pin 3 retain their nets. VCC changes from pin 5 to pin 6; pin 5 is explicitly NC in the schematic and unconnected on the PCB.
- Both positions, orientations, sides, and footprint UUIDs preserved. All 322 other footprints compare identically to the saved pre-edit board.
- D601 trace endpoints adjusted; IO3 corner rerouted. IO2 uses the existing connector via and one new 0.6 mm / 0.3 mm drill via, avoiding the new NC pad. Existing connections retained.
- D601 uses the KiCad DRY0006A solder-mask-defined land pattern, including negative mask/paste margins, with 0.15 mm local pad clearance to match its minimum copper spacing.
- Copper zones refilled. No zone boundaries or nets intentionally changed.

## Validation

- KiCad 9.0 CLI loads schematic and PCB successfully; updated PCB reopened in KiCad and D601 shown as TPD3E001DRYR / Manual:TPD3E001_DRY6.
- Exported netlist confirms every U801 and D601 pin mapping listed above.
- ERC before: 12 messages. After: 11 messages (1 existing error, 10 warnings); no new package-related errors.
- DRC before refill: 581 violations, 499 unconnected items. After replacement and refill: 177 violations, 499 unconnected items, zero footprint errors. Counts are not a direct quality comparison because original zone fills were stale.
- Final DRC has no new shorts or clearance violations involving the replacements. The existing D601-IO1 connector via still has a 0.25 mm drill below the configured 0.254 mm minimum; it was not changed.
- Refilling exposes several dangling-via warnings elsewhere on the unfinished board. This is a targeted package change, not a full-board routing or fabrication sign-off.

Confidence: high for package identity, pin mappings, and preserved placements (manufacturer datasheets, exported netlist, parsed board comparison); manufacturing availability and full thermal/EMC performance were not evaluated.

Local footprints are copied from the installed KiCad Package_SON library. The pre-edit target files are archived alongside this report. Existing user changes were preserved; no commit was made.

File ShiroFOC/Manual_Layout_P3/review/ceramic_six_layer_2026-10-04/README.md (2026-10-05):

# Ceramic DC link / six-layer revision evidence

See the [revision notes](../../../docs/PCB_CERAMIC_SIX_LAYER_2026-10-04.md) for the selected parts, circuit changes, stack target and remaining routing work.

- `schematic.pdf` and `schematic_*.png`: final KiCad schematic export; changed pages visually reviewed.
- `placement_front/back.svg/png`: native PCB geometry preview, viewed from the front through the board for coordinate consistency. Separate images show the components on each side and their courtyards. These show placement, not completed routing.
- `change_manifest.json`: capacitor population and added/restored schematic references.
- `placement_manifest.json`: exact positions, sides, orientations and old-net aliases.
- `bom.csv`: native KiCad BOM export, including DNP status and MPNs.
- `validation.json`: 21 passing revision invariants; existing DRC findings and unrouted items remain.
- `validation/`: native before/after ERC and DRC, compressed XML netlists and original copper checks for moved footprints.

`validate_revision.py` is read-only except for its JSON report. It uses the KiCad skill's S-expression parser and the pre-change ZIP under the project's backup directory. Netlist/ERC/DRC inputs are saved snapshots; regenerate them after any later CAD edit before relying on a rerun.

`update_schematic.py` and `update_pcb.py` are one-time migration records. **Do not rerun them on a later revision:** they reconstruct selected files from the temporary pre-change checkpoint and would replace subsequent edits. They are retained to explain how this revision was made. `render_placement.py` is a read-only renderer requiring KiCad's bundled Python/pcbnew.

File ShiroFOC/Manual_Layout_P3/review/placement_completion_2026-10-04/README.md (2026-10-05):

# P3 placement completion — 4 October 2026

The existing 219-footprint P3 PCB is now placed inside the original 80 × 80 mm outline. No test points, footprints, tracks, vias or copper pours were added. This is a placement completion, not a routing or fabrication release.

## Preserved work

- All 103 footprints already inside the outline are retained byte-for-byte, including their positions, rotations, sides, pads, fields and graphics. This covers the half-bridges, shunts, local passives, MCU/op-amp networks, crystal, placed decoupling, IMU, USB, bulk capacitors, connectors and mounting holes.
- All 286 pre-existing in-board track/via objects are retained byte-for-byte.
- U601 remains locked on B.Cu at the board centre: X 113.660312, Y 103.936331 mm. Its placed C601/C602 remain unchanged and locked.
- Board outline, net assignments, stackup, project rules, schematics and libraries are unchanged.

## Placement completed

116 previously parked footprints were placed by function:

- Brake MOSFET and gate driver below the bulk bank, with the comparator below them. Local comparator routing moved rigidly with its components.
- 10 V buck on the front left, with its input capacitors, bootstrap/VCC capacitors, inductor, output capacitors and feedback divider. Its existing PG via moved with U201 when the footprint changed from back to front.
- 5 V converter, supply mux and 3.3 V regulator on the back left. Their existing local routing moved rigidly with the corresponding subcircuits.
- CAN transceiver, protection and termination above the two bottom-edge CAN connectors.
- External encoder/Hall connector, ESD device, buffer and sensor power switch along the lower-right edge; feedback mux and compact bus-sense divider on the back nearby.
- Remaining ADC/temperature input filters beside the fixed MCU analog area, plus the brake NTC connector at the left edge on the back.
- Reset switch and status indicator above SWD; previously parked gate-driver supply capacitors beside the relevant MCU supply pins.
- DC-link protection and optional damping components on the back near the input/bulk region.

39 existing off-board copper objects moved with their owning parts; their shapes, widths, layers and net assignments were preserved. The sole reflection was the existing through via on U201's PG pin, following U201's B-to-F footprint flip. There was no rerouting.

## Section guides and layer intent

The PCB contains labelled non-copper section boundaries:

| KiCad layer | Contents |
| --- | --- |
| User.1 | Front sections: DC link, input, brake, auxiliary power, MCU/analog, IMU, half-bridges, USB/UART, CAN, external feedback, reset/status and SWD |
| User.2 | Back sections: DC-link protection, supplies, centred encoder, fixed MCU/op-amp network, temperature filters, brake NTC, feedback mux and fixed bridge routing |
| User.Comments | Placement scope and copper-layer intent |
| User.Drawings | 8 mm mounting-hardware envelopes |

Enable User.1 or User.2 in KiCad's Appearance panel to inspect a side's guides. They are visual aids, not copper zones or enforced keepouts. Front and back preview images use the same top-view coordinates.

Copper-layer intent follows the user's instruction: F.Cu for high-power distribution; In1.Cu for internal signals and low-voltage power; In2.Cu reserved for GND; B.Cu for signals and GND. No planes were created or filled during this pass.

## Checks

| Check | Result |
| --- | --- |
| Footprints | 219 retained; 103 fixed and 116 moved |
| Test points | 0 on PCB; none added |
| Existing routing | 252 segments and 73 vias retained |
| Protected footprint/copper native text | Exact byte-for-byte preservation |
| Physical copper connectivity | All 601 connected components identical before/after |
| Present PCB pad-net assignments vs native schematic netlist | 0 mismatches |
| New DRC violations | 0 |
| Existing DRC findings | 144 → 127; 17 resolved |
| Shorts / overlapping courtyards | 0 / 0 in final native DRC |
| Unconnected items | 412 → 412, expected for this unrouted placement stage |
| Newly placed components | Inside the outline; hardware and opposite-side through-pad interference checked |

The 127 remaining findings are inherited: 11 clearances, 34 dangling vias, 20 dangling tracks, 17 library-footprint mismatches, 37 silk overlaps, 5 silk-over-copper findings and 3 silk-edge clearances. Protected work and design rules were not changed to suppress them.

The schematic contains 33 test points and feedback capacitors C414/C424/C434 that were absent from the starting PCB. They remain absent; the user explicitly requested no test-point placement. No schematic-to-PCB import was performed.

## Evidence and recovery

- [Front sections](sections_front.png) and [back sections](sections_back.png)
- [Front geometry](placement_front.png) and [back geometry](placement_back.png)
- [Native final DRC](final_drc.json) and [comparison with baseline](drc_comparison.json)
- [Byte preservation](preservation_check.json) and [native geometry/connectivity validation](geometry_validation.json)
- [Placement manifest](placement_manifest.json)
- [Pre-placement project backup](before_placement.zip) and [exact baseline PCB](baseline.kicad_pcb)

`build_placement.py` generates a review candidate from the checkpoint using KiCad 9's bundled Python. `assemble_final.py` uses Python 3.12 to replace only the explicitly movable objects and add guide drawings, preserving the remaining native source text. `validate_geometry.py` checks the result using native KiCad geometry/connectivity. These scripts do not overwrite the working board. Re-running them rebuilds the review outputs from the checkpoint; it does not incorporate subsequent manual edits.

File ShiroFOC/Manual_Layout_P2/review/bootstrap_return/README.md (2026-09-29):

# Bootstrap return correction — 27 September 2026

Applied to the user's P2 save at 11:19. `before.zip` preserves all modified electrical/project files before this correction. Older projects remain unchanged.

## Connections

| Phase | Bootstrap cap | BOOT pin | Dedicated return | Driver OUT pin | MOSFET SH pin | Motor-current net |
|---|---|---|---|---|---|---|
| U | C4 | U4.41 | HS_RETURN_U | U4.42 | U1.2 | PHASE_U |
| V | C8 | U4.38 | HS_RETURN_V | U4.39 | U2.2 | PHASE_V |
| W | C12 | U4.35 | HS_RETURN_W | U4.36 | U3.2 | PHASE_W |

Each capacitor pin 2 connects to BOOT; pin 1 connects to its dedicated return. The phase nets retain MOSFET VSW pads 3–11 and the relevant J1 terminal. The dedicated returns and phase power nets join internally in the MOSFET package; keep them separate on the PCB. Route each high-side return alongside its gate trace. Put bootstrap capacitors at the driver pins. No capacitance values or footprints changed.

C4/C8/C12 moved from the bridge schematic sheet to the gate-driver sheet, drawn directly between BOOTx and OUTx. Their PCB symbol paths were migrated to the actual parent sheet instance. Net classes: HS_RETURN_* = Gate; PHASE_* = Power.

All 260 physical placements and layers are unchanged from the latest user save. The user had already moved the MCU and bootstrap capacitors closer together; that work was retained. No routing was added or removed.

## Previous NTC annotation repair

The prior addition used child-file UUIDs where parent sheet-instance UUIDs were required. After the schematic was opened, its five part references reset to '?'. Restored J502, R511, R512, C505 and D505 by their preserved symbol UUIDs and corrected their instance paths. All symbol-instance paths across the hierarchy were checked against their parent sheet instances, not just against ERC.

## Checks

- Native ERC: 0 violations.
- Pad-net cross-check: no mismatches; known U205 pins 19/20 without footprint pads remain.
- PCB DRC: 34 violations, unchanged from the latest user save; zero added findings. Unconnected items remain expected on this unrouted board.
- Schematic parity: reduced from 11 issues to the two existing U205 missing-pad warnings.
- All component positions, angles, sides and existing routing preserved.
- Gate-driver and bridge sheet renders inspected for connectivity and readable placement.

This is a scoped return-path correction, not a fabrication-release review. Current machine reports are in this folder and copied to `../current.xml`, `../erc.json`, and `../drc.json`. Earlier reports/previews describe earlier placements. The one-shot apply script is an audit record, not a reusable rebuild command.

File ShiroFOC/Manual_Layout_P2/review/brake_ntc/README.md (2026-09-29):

# Optional external brake-resistor NTC input

Updated P2 schematic and placement, 27 September 2026. The older Manual_Rebuild/P1 projects remain unchanged; `before.zip` preserves the pre-change P2 files and firmware requirements.

## Circuit and pin allocation

- J502: JST GH SM02B-GHS-TB, standard KiCad footprint and generic library model. Pin 1 = probe, pin 2 = quiet GND. Optional passive external 10 kΩ-at-25°C NTC; no external probe part is included in the board BOM.
- R511: 10 kΩ, 1%, 0603, pull-up to 3V3.
- R512: 4.7 kΩ, 1%, 0603, series input current limiting/filter resistance.
- C505: 100 nF, 16 V, X7R, 0603, to GND at the ADC end.
- D505: BAT54S, SOT-23 rail clamps. Pin 1 = GND, pin 2 = 3V3, pin 3 = ADC. This is basic transient input conditioning, not isolation or protection against connecting the probe to VM/brake power terminals; ESD performance is not qualified.
- PC2 / STSPIN pad 11: ADC12_IN8; `NTC_BRAKE`.
- Status LED moved from PC2 to PC15 / STSPIN pad 5. Active-low sink, open-drain/low-speed; R304 changed from 1 kΩ to 2.2 kΩ. TP1021 relabelled `STATUS_LED_N`. PC15 is no longer spare.

The probe must be thermally attached and electrically insulated from resistor power terminals. Its insulation, adhesive and sensor temperature range must suit the actual resistor body. 5 cm leads are suitable; use a twisted pair away from switched-current wiring. The external probe's actual curve and temperature rating remain an installation choice, not an assumed B3380/B3950 interchangeability.

## Nominal calculations

`Vadc = V3V3 * Rntc / (10000 + Rntc)` neglecting input and diode leakage. At 25°C with a 10 kΩ probe: 1.65 V for 3.3 V supply. A short tends to 0 V; open tends to 3.3 V. Scale against the actual ADC reference. Clamp leakage, especially at high PCB temperature, introduces error and must be included in threshold validation.

`tau = (4700 + (10000 || Rntc)) * 100 nF`: 0.97 ms at 25°C (164 Hz pole), 1.47 ms at open circuit (108 Hz pole). These are electrical filter values, not sensor response times. Maximum nominal probe self-heating is about 0.272 mW at Rntc = 10 kΩ and 3.3 V. Firmware starts with >=10 ms electrical settling and 20 Hz acquisition without disturbing FOC sampling. Use measured thermal lag and the selected probe curve to choose final filtering/thresholds.

PC15 sinks below 1.65 mA even with a shorted LED at 3.6 V and 2.2 kΩ. Include PC14's input-mux pull-up current in the PC13–PC15 shared 3 mA budget; do not use PC15 as an LED current source. Keep LSE disabled.

## Firmware behavior

Updated [firmware requirements](../../../requirements/FIRMWARE_REQUIREMENTS.md): FW-TEMP-02/03/04, FW-LED-01 and resource map. Probe presence is explicitly configured. An unplugged optional probe reports unavailable; loss of a configured probe faults. Temperature supplements the brake energy budget and requests early regeneration derating. It must not disable the independent bus-overvoltage clamp. A connected temperature probe does not prove power-resistor continuity.

## Verification and limitations

- Native ERC: zero violations.
- Native PCB DRC: same 27 pre-existing violations and two U205 missing-pad parity warnings; no added DRC findings after placement cleanup.
- All new pad nets and the PC2/PC15 remap cross-checked against native schematic export.
- Existing footprint positions, angles and sides preserved; five new parts are on the back. No traces, vias or planes added.
- Rendered MCU and brake sheets inspected; bottom layout preview inspected separately.
- This is a scoped schematic/placement addition, not a complete power-stage, EMC, thermal, sourcing or fabrication review. Existing issues in `../OPEN_ITEMS.md` remain.

Sources: STSPIN32G4 local datasheet pin table (PC2, pad 11, ADC12_IN8); [STM32G431 datasheet](https://www.st.com/resource/en/datasheet/stm32g431cb.pdf) pin table and PC13–PC15 drive note; [BAT54S datasheet](https://assets.nexperia.com/documents/data-sheet/BAT54S.pdf) pinning. Standard KiCad connector, SOT-23 and 0603 footprints used.

Migration scripts are one-shot audit records and depend on the local KiCad runtime/helper; do not rerun them over manual edits. Subsequent schematic-only drawing cleanups and final new-part placement shifts are included in the native files and final reports.

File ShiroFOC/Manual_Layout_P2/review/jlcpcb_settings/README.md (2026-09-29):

# PCB editor routing defaults — 2026-09-27

Current project: Manual_Layout_P2. Previous settings and board preserved in before.zip.
Source: https://jlcpcb.com/capabilities/pcb-capabilities (checked 2026-09-27).

## Via and routing rules

- Project minimum drill: 0.20 mm; minimum via diameter: 0.45 mm; minimum radial annular width: 0.10 mm.
- Default, Analog and USB netclasses: 0.50 mm diameter / 0.25 mm drill.
- Gate, LogicPower and Power retain 0.60 / 0.30 mm defaults.
- Selectable presets: 0.50/0.25, 0.45/0.20 and 0.60/0.30 mm (diameter/drill).
- Via hole-to-hole edge spacing: 0.20 mm. Existing component-pad drill spacing rule: 0.45 mm; existing U901 thermal-hole rule retained.
- Minimum track width and copper clearance: 0.15 mm, matching the stated multilayer 2 oz limits. Existing netclass clearances remain larger.

JLCPCB publishes an absolute via/drill minimum of 0.25/0.15 mm, but this project intentionally uses stricter practical minima. Its table charges extra for 0.15 mm holes and for 0.20/0.25 mm holes with via pads below 0.45 mm. The chosen sizes avoid those categories. A via preset does not establish a high-current rating: power transitions still need appropriately sized parallel arrays.

## Placement

Applied and saved editor grid: 0.10 mm. Option+1 selects 0.10 mm; Option+2 selects 0.05 mm for fine placement. These are editing increments, not component-clearance rules.

This is a focused routing-default update, not fabrication sign-off. Existing footprint and unfinished-layout DRC issues remain to be resolved.

## Verification

KiCad loaded and saved the settings. Readback confirmed all three presets and netclass defaults, plus grid indices 18/19 for 0.10/0.05 mm. The PCB file is byte-identical to its pre-change backup; no geometry, placement or routing changed.

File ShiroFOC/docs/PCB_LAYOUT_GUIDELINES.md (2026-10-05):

> **Active P3 revision (2026-10-04):** use `Manual_Layout_P3/ShiroFOC_Manual.kicad_pro` and the [ceramic / six-layer revision](PCB_CERAMIC_SIX_LAYER_2026-10-04.md). It supersedes older capacitor, layer and placement coordinates below. The PCB is partially routed.

> **P1 update (2026-09-17):** follow [PCB_REVISION_LIST_P1.md](PCB_REVISION_LIST_P1.md) for the reclaimed top-side centre, four M3 corner mounts, parallel bridge/output rows and capacitor proposal.

> **Current placement (2026-09-19):** use [ShiroFOC_KiCad_P1](../ShiroFOC_KiCad_P1/ShiroFOC_KiCad.kicad_pro). [P1 notes](PCB_PLACEMENT_P1.md) supersede older placement coordinates and capacitor-replacement proposals. The original P0 project is retained.

# ShiroFOC PCB layout plan and guidelines

Date: 2026-09-16; revised to user mechanical/DRC constraints  
Basis: A1 connected drawing / A0 electrical design; KiCad 9.  
Status: placement and routing plan, not a routed-board or fabrication approval.

## 1. Design intent and priorities

Use this document alongside the [existing layout handoff](PCB_LAYOUT_HANDOFF.md), [design review](DESIGN_REVIEW_REV_A.md), [pin allocation](MCU_PINOUT_AND_INTERFACE_PLAN.md), and [firmware contract](FIRMWARE_BRINGUP_CONTRACT.md). The schematic/netlist defines connectivity; layout must not silently merge or change nets. Sheet-local aliases are recorded in `ShiroFOC_KiCad/outputs/net_name_aliases.json`.

- Six layers, **2 oz finished outer copper / 0.5 oz inner copper**, double-sided assembly.
- Scope: proceed with the existing part selections and supplied manufacturing limits. **Skip part-availability validation and external fabricator/assembler validation** in this layout workflow. Retain internal electrical, mechanical and DRC checks.
- Outline: compact **rounded square, no larger than 150 × 150 mm**. U601 is centred on the back; U301 and the MOSFETs are on top, with U301 offset from U601 to reserve space beneath U301 for decoupling and ADC parts.
- Default stack: **signal/power – GND – signal – power – GND – signal/power**. Use broad outer-layer copper for motor power and local rails.
- Put compact analog networks and suitable decoupling on the underside near U301's corresponding pins. Bottom-side shunts are an option subject to the loop, thermal and assembly checks below.
- Prioritise: mechanical encoder alignment and cooling; bridge commutation loops; shunt sensing; gate drive; converter loops; analog references; interfaces; remaining signals.
- The 18–42 V operating range and 25/40 Arms objectives remain design targets. Trace width, copper weight and clean DRC alone do not establish a continuous-current rating.
- Keep the three phase cells geometrically similar, but do not lengthen a critical loop merely to achieve visual symmetry.

## 2. Stackup, ground and fabrication constraints

| Layer | Intended use | Rules |
|---|---|---|
| L1 / F.Cu | Main power stage, components, local power pours, signals | 2 oz finished copper; compact switch nodes; L2 provides signal reference. |
| L2 / In1.Cu | Continuous GND, 0.5 oz | Preserve under logic, analog and top-side interfaces. No general signal routing or power islands. |
| L3 / In2.Cu | Signals, 0.5 oz | Close reference to L2; keep sensitive routes clear of the power cells. |
| L4 / In3.Cu | Power distribution, 0.5 oz | Close to L5; supplement with broad outer copper for motor current. |
| L5 / In4.Cu | Continuous GND, 0.5 oz | Bottom-side signal reference. Stitch to L2 and outer ground. |
| L6 / B.Cu | Encoder, analog, decoupling, ceramic banks and signals | 2 oz; keep the motor-current return outside the encoder/analog region. |

### Stackup selection

- Copper weights are fixed: **2 / 0.5 / 0.5 / 0.5 / 0.5 / 2 oz** from top to bottom. The inner planes provide reference/return continuity; do not assume they have the current capacity of the outer copper. No copper-weight or availability validation task is required.
- Prefer thin L1–L2 and L5–L6 dielectrics, close L2–L3 and L4–L5 spacing, and the thicker central dielectric between L3 and L4. This improves local return coupling on both sides.
- Record the selected stackup identifier, board thickness, finished copper, dielectric thicknesses and impedance calculation in the PCB design notes before routing USB.
- Keep L2 and L5 as continuous GND. L3 references L2 and L6 references L5; do not route sensitive signals across ground cutouts. L4 supply islands do not replace either ground plane.
- Use the self-contained DRC baseline in section 19, transcribed from the supplied screenshots where available. Additional project choices are labelled separately. Do not import 1 oz routing minima or require a fabricator-validation step.

### Ground and return paths

- Keep one electrically continuous GND system. Separate noisy and quiet circuits by placement and short return loops, rather than cutting an analog/digital ground moat.
- Establish a broad power-return corridor between bridge shunts, local capacitors, brake stage and DC input. Keep the MCU/ADC area outside that corridor. Ground-plane current distributes according to impedance; naming a region “quiet” does not keep power current out of it.
- Stitch L2/L5 together near signal layer transitions, IC decouplers, connector protection and local power returns. Put a ground-return via beside a signal transition where practical; never substitute a switch-node via for a ground-return via.
- Avoid rows of antipads forming slots across a signal return corridor. Inspect filled copper on each layer, especially around shunt and MOSFET via arrays.
- Keep continuous reference copper beneath SPI, USB, CAN logic and analog routes. Consider only **small, deliberate local plane clearances** beneath high-dv/dt switch islands where the device guidance or EMI assessment justifies them. No signal may cross those clearances. Do not blanket-remove ground beneath entire power-stage or converter regions.
- VM thermal vias must clear both GND planes. Source-above-shunt vias must also clear GND. A thermal via is electrically part of its pad net.

## 3. Mechanical floorplan and double-sided assembly

- Fix the AS5047P magnetic centre, magnet axis, air gap and rotating-part clearance first. Establish mounting holes, connector mating envelopes, heatsink, insulation and enclosure height on both sides.
- Use a rounded-square Edge.Cuts outline, width = height, **at most 150 mm per side**. Begin with an **80 × 80 mm trial floorplan and 5 mm corner radius** (project starting choices, not committed dimensions). Shrink or grow after establishing the revised edge-bulk/local-ceramic arrangement, four corner mounts and complete phase cells; choose the smallest practical square that preserves electrical, thermal and mechanical space. Never exceed 150 × 150 mm.
- Put the **magnetic sensing centre of U601 on B.Cu at the board geometric centre**; account for any package-to-sensing-centre offset and bottom-side orientation. Fix this location before placing the other circuits. The magnet is outward from the underside sensor, not through the PCB. Reserve only the actual underside component/rotating-part height clearance; do not exclude the top-side centre from placement.
- Put **U301 and Q401–Q403 on F.Cu**. Offset U301 laterally from the centre so its underside decoupling/ADC region does not physically overlap U601 or its underside assembly clearance. Determine the offset from both footprint courtyards and component clearances, not from an arbitrary fixed distance.
- Keep power switching, inductors and high-current paths away from the central encoder on both sides. Arrange the power cells toward an edge and the MCU toward their quiet side; use perimeter connectors. Do not route a motor-current shortcut through the encoder region. Keep optional bottom shunts beneath their phase cells and outside the central sensor envelope.
- Place the three half bridges near the phase-wire exit and DC-link bank. Place U301 with its gate-drive side facing the bridges and analog side facing the sense routes. Keep logic connectors toward the quiet region.
- Reserve underside areas under U301 for pin-local decoupling and ADC networks; reserve separate underside areas under bridge cells for optional shunts. Do not overlap these functions.
- Keep underside components out of mounting hardware, heatsink, insulation-pad compression and test-fixture contact areas. Maintain rework access and realistic component height clearances.
- Avoid placing an ADC resistor network directly beneath a hot inductor, MOSFET or shunt even if its XY coordinates look convenient.
- Account internally for bottom-side shunt retention during second reflow and the heavy top-side parts/process sequence. Check stencil aperture balance and solder wicking at power pads; no external assembler-validation gate is included.
- Use filled/capped via-in-pad only where the selected process supports it. Ordinary open vias in solder lands can drain solder; tenting alone is not equivalent to filled/capped via-in-pad.
- Add fiducials, tooling/panel clearances and visible polarity/axis markings on the required assembly sides. Keep test points accessible after the heatsink and connectors are installed.

## 4. DC input, bulk capacitors and bus measurement

P3 approved revision: C101-C103 are now part of a 48-fitted / 6-DNP Samsung CL32Y106KCVZNWE ceramic bank. See [ceramic / six-layer revision](PCB_CERAMIC_SIX_LAYER_2026-10-04.md) for reference groups, DC-bias limitations and the external-bulk attachment option.

**J101, C101–C106, D101, R102/C107, VM divider and C108.**

- Route J101 to a broad VM/GND distribution with the bulk bank adjacent to the inverter. Keep outgoing and returning high-current paths close to reduce loop area; avoid long separated rails.
- Distribute ceramic-bank VM/GND connections with comparable low-inductance paths. Allow for the selected 2.5 mm body height, reflow access, board flex and hot copper; validate ripple-current sharing and temperature.
- Place small bus ceramics where current commutates, not merely beside the input connector. Bulk capacitors do not replace package-local ceramics.
- Keep DNP clamp and damping positions electrically short enough to be useful. A long branch to an optional TVS or RC network adds inductance. Preserve access for an external low-inductance capacitor bank.
- Connect voltage-divider pickup to the intended DC bus, away from phase and brake switching islands. Put the high-voltage resistor chain toward the bus and keep the divided, high-impedance node short and shielded by quiet ground.
- Preserve resistor-to-resistor voltage spacing and distance to nearby low-voltage copper; account for working voltage, transient envelope and contamination when setting clearance rules.
- Place the final ADC capacitor C108 near PA0/U301; route through the existing TMUX channel as drawn. Do not bypass the power-off isolation provided by the mux.
- Input polarity marking must be unambiguous: J101 pin 1 GND, pin 2 VM. Reserve strain relief and soldering access. Existing external fuse/precharge requirements remain in the design review.
- Verify bulk ripple and temperature in hardware: the ceramic bank has no validated aggregate ripple-current rating and may limit operating current, independent of PCB copper capacity.

## 5. Three half bridges and high-current copper

**Q401/Q402/Q403; phase U/V/W cells.**

- Place each MOSFET package, its local ceramics and shunt as one tightly coupled cell. Trace the physical loop: local VM capacitor → high-side device → low-side device → shunt → capacitor GND. Minimise enclosed area and inductance, not just individual trace lengths.
- C412/C422/C432 (1 µF) return to common **GND below the shunts**. C415/C425/C435 (10 nF) connect VM directly to each package's **source/PGND above its shunt**. Preserve this intentional distinction.
- Put the 10 nF package bypass directly at the relevant package terminals, ideally on the same side. Place the 1 µF capacitor to minimise the complete bridge/shunt loop; evaluate a bottom-side location only with its transitions included.
- Use short, broad pours for VM, phase and force paths. Avoid thin necks at pad exits, corner connections, via arrays and connector pads. Connect all designated power pads; do not rely on a single lead into a large pour.
- Use the second outer layer for parallel current paths where helpful, with distributed via arrays at both ends. A large lower pour connected through one tiny neck or a few remote vias contributes little.
- Size conductors using actual RMS/peak current, duty cycle, copper thickness, length, allowable drop and temperature rise. Calculate I²R loss and check terminal temperatures. Do not use a universal “amps per via” rule.
- Keep phase-node copper only as large as needed for current and heat. Avoid unnecessary overlap with sensors, analog networks, crystal and interface traces on other layers.
- Keep optional snubber R415/C413, R425/C423 and R435/C433 immediately beside their corresponding switching devices and return points. Preserve short pads for probing and later tuning.
- High-current SMD pads should use solid copper connections or specifically engineered thermal connections, rather than default narrow thermal spokes. Check solderability in the layout; treat through-hole connector heat balance separately.
- CSD88599 pad 27 and its thermal vias are **VM**, not GND. Its exposed metal requires an electrically verified heatsink interface; use suitable insulation for a shared heatsink/chassis. Follow the actual package drawing for NC and power pads. [TI CSD88599Q5DC](https://www.ti.com/product/CSD88599Q5DC).

## 6. Bottom-side shunts and Kelvin routing

**R416/R426/R436, 0.5 mΩ four-terminal shunts.**

Bottom-side placement is acceptable if it improves the total cell geometry and passes these checks; “plenty of vias” alone is insufficient.

- Place each shunt immediately below/adjacent to its own bridge return. Use a broad **source-side force via bank** into force pad 1 and a separate broad **GND-side force connection/via bank** from force pad 4. Follow the actual netlist if the footprint is rotated or flipped.
- Keep these two force conductors separate on **every layer**. Source-side copper must never touch a GND plane or common return before crossing the resistor. That would bypass the measurement.
- Distribute vias across the force-pad connection width for current spreading. Check copper between holes, barrel plating, finished hole size, solder wicking, array temperature and both top/bottom neck-downs. Include the added through-board inductance in the commutation-loop review.
- Pads 2 and 3 are the dedicated sense connections. Start a separate trace at each sense pad. Do not merge either into adjacent force copper or share its power vias. Preserve any intentional net separation in the footprint/netlist.
- Route SENSE_P and SENSE_N together along the same quiet corridor, with similar exposure and as few transitions as practical. If a transition is needed, use one dedicated via per sense trace, adjacent to each other and away from force-via current crowding.
- The negative Kelvin trace is **not a spare GND connection**, even when near ground potential. Route it all the way to its matching amplifier network.
- Keep pairs away from gate loops, phase copper, buck inductors and brake switching. Avoid long parallel runs with these nets. A 90° crossing is only a fallback and does not remove capacitive coupling.
- Prioritise a small pickup loop and balanced routing over exact length matching; do not add serpentine tuning to low-frequency analog sense pairs.
- Allow cooling copper on the force terminals per the shunt manufacturer's guidance, while preserving the sense geometry. Do not pour copper across the resistive element or sense isolation.
- At 40 Arms, 0.5 mΩ dissipates 0.8 W; pulse and terminal-temperature limits still apply. Keep shunt heat away from the IMU and gain resistors, and consider bottom airflow/enclosure clearance.
- Review the complete top-to-bottom loop before accepting this placement. If it produces excessive inductance, temperature or assembly difficulty, move the shunt beside its bridge on top.

## 7. Gate drive, bootstrap and hardware protection

**U301 driver section, gate resistors/pulls, C411/C421/C431 and SCREF network.**

- Place each series gate resistor at the MOSFET gate terminal so the resistor-to-gate segment is very short. Keep gate pull-downs local to their gate/source connection.
- Route gates short with a nearby appropriate return. High-side gate return is the corresponding OUT/phase node. Keep the OUT connection to U301 short and take it from the device region, not the far end of the motor connector trace.
- U301 has shared ground references in this circuit: place its driver ground/decoupling toward the local bridge-return region, minimising common-source inductance. Do not invent a separate low-side source pin or connect U301 GND to a source-above-shunt net to imitate a dedicated Kelvin driver.
- Keep gate routing away from Kelvin pairs and amplifier inputs. Avoid vias if practical; where necessary, minimise the entire gate/return loop rather than routing one conductor on a long detour.
- Use adequate gate width for pulse current and low inductance; gate nets do not need motor-current-sized pours. Avoid unnecessarily large copper that couples switching noise.
- Bootstrap capacitors connect **BOOT to the matching OUT**, never to GND. Place at the driver pins with short connections, away from analog inputs. Treat their pads/traces as moving with the phase potential.
- Keep VCC decoupling directly at driver supply/ground pins. Do not feed a chain of decouplers through one long thin trace or shared ground via.
- Put SCREF R310–R312/C314 close to U301 with quiet local ground; keep switch-node and gate copper away. Preserve the distinction between VDS protection and shunt-based current measurement.
- Provide accessible gate/source and phase/bus probe locations with short return access. Use differential probing for floating high-side nodes; keep large test-pad stubs off critical loops.
- Validate gate-source overshoot/undershoot, drain overshoot, ringing and dead time at increasing current. Final gate/snubber values are measurement-dependent.

## 8. U301 MCU supplies, ADC networks and crystal

### Decoupling and underside placement

- Place each local capacitor next to the power pin it serves. Judge the full pin → capacitor → ground return loop, including vias, rather than the component's distance to the centre of U301.
- Bottom-side placement directly under the relevant peripheral pin is preferred where it gives a short loop. Use nearby supply and ground vias, with the ground via immediately beside the capacitor ground pad. Avoid a remote shared via serving many capacitors.
- Do not crowd the exposed-pad thermal-via array with bottom parts or via escapes. Respect solder-process clearances. Keep gate/switch routing out of the underside analog area.
- If a same-side capacitor has a materially shorter high-frequency loop, keep it on top. Compactness is secondary to decoupling effectiveness.
- Place bulk local capacitance nearby after the pin-local ceramics. Give VDDA/VREF filtering and C303–C306 their own short quiet branches; keep R301/R302 near the loads they filter.
- Preserve the external 3V3 bypass wiring to REGIN and the existing STSPIN supply connections. Do not treat REGIN as a buck feedback input. [STSPIN32G4 datasheet](https://www.st.com/resource/en/datasheet/stspin32g4.pdf).

### Current amplifiers and other ADC channels

- Put R417–R419 / R427–R429 / R437–R439, R410/R420/R430 and R441–R443 next to their actual op-amp pins, preferably underneath the corresponding analog edge of U301.
- Keep feedback resistors and DNP feedback capacitors immediately around their amplifier pins. Make the feedback loop short; route amplifier output away from the sensitive input until it reaches the intended connection.
- Keep each channel compact with comparable thermal surroundings. Match resistor specification and technology; avoid placing one ratio resistor over hot copper and its partner over cool ground.
- Route VREF bias quietly, with local decoupling as drawn. Do not use its path for digital load currents. Keep input pairs separate from amplifier outputs and reference distribution.
- Put final RC filtering at the receiving ADC pin. Temperature sensors themselves stay at the heat sources; their filter capacitors/pull networks can occupy the MCU underside.
- Preserve component values and RC topology. Additional filtering changes acquisition settling and fault response and requires schematic/firmware review.

### Crystal, reset and boot

- Keep Y301 and C308/C309 close to PF0/PF1, preferably on the same side as U301. Keep oscillator traces short, compact and separated from gates, inductors, USB and clocks.
- Pads 1/3 carry the crystal signal; pads 2/4 are grounded case pads. Give load-cap grounds short local returns; keep unrelated routing out of the oscillator area on adjacent layers.
- Do not add oscillator test pads or long stubs. Preserve load-capacitance assumptions and verify startup over supply/temperature after assembly.
- Place PB8 pull-down R307 near U301 and U602 nearby. Keep the PB8/common-mux route short with no test stub. Keep reset pull/filter and boot controls short and away from power switching.

## 9. STSPIN VCC buck and auxiliary 5 V converter

### VCC converter around U301, L301 and D302

- Place the input bypass, switching pins, diode and inductor as a compact block on the driver/power side of U301. Keep the switching loop out of the ADC/crystal region.
- Put local input and output capacitor returns near the relevant driver ground connection, with short vias into the ground planes. Keep VCC_SW small and away from sense/SCREF/reference routing.
- Follow the ST layout example for the diode, inductor, exposed-pad ground connection and thermal spreading; retain the selected inductor's footprint keepout. The existing 22 µH choice still needs hardware startup/ripple verification. [ST AN5953](https://www.st.com/resource/en/application_note/an5953-stspin32g4--buck-converter-design-guidelines--stmicroelectronics.pdf).

### LMR36510 5 V supply, U201

- Place the high-frequency input ceramic directly across VIN/PGND with a tiny switching-current loop. Keep IC, bootstrap capacitor, inductor and output capacitor grouped on the same side where possible.
- Keep the switch node compact. Sense output voltage after the inductor at the output-capacitor region; route FB back through quiet copper and place the divider near FB.
- Keep feedback and enable/high-impedance nodes away from the inductor and SW. Return the divider to the local quiet IC ground region, without sharing an input switching-current neck.
- Connect the exposed pad and GND correctly for both heat and electrical return. Preserve continuous reference copper except any narrowly justified switch-node keepout.
- Keep converter heat away from the IMU and analog gain networks. Check inductor clearance, saturation margin and the Wurth footprint's central top-copper keepout. [TI LMR36510 datasheet](https://www.ti.com/lit/ds/symlink/lmr36510.pdf).

## 10. USB/buck power mux and 3V3 LDO

**U203 TPS2121, U204 TLV75533PDYDR.**

- Arrange USB 5 V and buck 5 V into separate short input paths, then a short 5V_SYS path to the LDO. Keep all nets distinct; copper must not bypass mux reverse blocking.
- Put each mux input capacitor at its respective input and the output capacitor near OUT. Route current-carrying pins broadly; place threshold, current-limit and timing components near their pins and away from switch-node copper.
- Preserve USB priority and power-off behaviour from the schematic. Provide test access to each input, 5V_SYS and 3V3. [TI TPS2121 layout guidance](https://www.ti.com/lit/ds/symlink/tps2121.pdf).
- Place LDO input/output capacitors close to U204 with short ground loops. Use the **DYD** footprint and repeated pad 2/GND thermal land; do not replace it with a plain five-pin SOT23 footprint.
- Provide ground copper and thermal vias for the LDO while keeping it outside the hot bridge area. Review the documented approximately 0.49 W nominal allowance and 0.624 W fault allowance against actual enclosure temperature.
- Distribute 3V3 with short adequate-width branches; feed analog filtering from a quiet branch. Do not route sensor supply through a narrow CAN/transceiver supply neck.

## 11. Brake chopper and independent overvoltage circuit

**Q501, U501, D501–D504, U502, J501 and R506–R510.**

- Put Q501 and J501 near the power bus. Keep the VM → external resistor connection → Q501 → GND current path compact on the board, with a broad return to the DC-link region.
- Place D504 close to the connector/switch/VM loop so lead-inductance recirculation does not traverse a long board trace. Keep BRK_SW copper small and away from analog, feedback and communications.
- Place U501 near Q501, its decouplers directly across its supply/GND, and the gate resistor/GS clamp near Q501. Route a dedicated low-current source return from Q501 source region to the driver ground, without sharing a long high-current source neck.
- Q501 pads 1–3 are source, 4 gate, 5–8 and the large drain land are drain. Thermal copper/vias on the drain are BRK_SW, not GND; limit unnecessary capacitive coupling.
- Put U502 and its reference/filter/hysteresis network in quiet copper, outside the switching loop. Route VM pickup from the bus and keep the three series high-voltage resistors' clearances and the comparator input node compact.
- Preserve diode-OR wiring and hardware brake operation during MCU reset. Keep control pull-downs local and provide comparator/control test access without long sensitive-node stubs.
- Mark J501 as VM and BRK_SW; both wires are bus-voltage conductors. Provide strain relief and twisted-lead routing space. Resistor cooling belongs off-board; do not put its heat into the logic region.

## 12. Position feedback: AS5047P, external Hall/ABI and TMUX1574

- Fix U601 on the **back side with its sensing centre at the rounded-square board centre**, using mechanical magnet geometry, package sensor-centre offset and bottom-side orientation. Verify air gap, magnet dimensions, runout and tolerances against the encoder guidance before fixing the outline.
- Keep inductors, high-current conductors and magnetic/ferromagnetic hardware away from the sensor. Ground copper is not a shield against low-frequency magnetic fields; reduce loop area and increase physical separation.
- Put encoder supply capacitors close to the correct supply pins. Respect the existing supply mode and do not connect internally regulated pins differently for routing convenience.
- Route ABI signals from U601 through the selected series components to U602, then short paths to TIM4 pins. Avoid switch-node coupling that could create false counts. Preserve source termination positions and hardware default pulls.
- Place U602 near the MCU; keep its fourth-channel VBUS analog path away from the clock/ABI branches where practical. Keep PB8 particularly short as described above.
- Put D601 at J601, ahead of downstream signal resistors, with a short ground discharge path. Its pin 5/C604 net is **FB_ESD_RAIL**, not 3V3; keep that isolated rail compact.
- Keep optional Hall pull-ups accessible for population changes. Mark J601's 0–3.3 V input and 3V3-output contract. Route cable-related ESD currents near the connector rather than through the MCU region.

## 13. Shared SPI and BMI323 IMU

- Place SCK/MOSI series resistors at U301; route a compact shared bus with short branches to the two slaves. Avoid an unnecessarily large star or long dangling branches.
- Put each MISO series resistor near the sensor that drives it. Keep chip-select pulls at their receiving devices and ensure neither branch is left floating during reset.
- Route SPI over uninterrupted ground and away from power loops. Exact length matching is less important than short branches, continuous returns and signal integrity at the selected clock rate; avoid ornamental meanders.
- Place U701 in a quiet, mechanically stable region, away from board edges that flex, screws, connectors, breakaway tabs, inductors and hot parts. Align and mark its axes relative to the board/mechanical assembly.
- Place IMU supply decoupling beside its pins, with short ground connections. Keep INT1/INT2 away from noisy copper and route them over ground.
- Do not put through vias in the BMI323 package footprint area. Maintain Bosch's land, soldermask and paste requirements; avoid solder beneath unintended package areas. Check panel separation and screw loading for strain. [Bosch BMI2xy/BMI3xy handling and mounting guidance](https://www.bosch-sensortec.com/media/boschsensortec/downloads/handling_soldering_mounting_instructions/bst-mis-hs001-2.pdf).
- ABI provides timer-based control feedback; shared SPI remains available for sensor/configuration traffic. Layout still needs clean digital edges, and firmware retains the documented per-device SPI mode and scheduling requirements.

## 14. Phase temperature sensing

**TH701/TH702/TH703 and their ADC filters.**

- Associate the sensors with U/V/W explicitly in PCB text and assembly documentation. Place each near representative MOSFET thermal copper, with similar thermal coupling across phases.
- Keep thermistor terminals electrically isolated from VM/phase copper. Thermal proximity does not authorise a copper connection to a hot electrical node.
- Prefer short, quiet sensing paths; place ADC-side capacitors near U301. Route away from gate/phase edges and do not share the sense ground return with a high-current neck.
- Check that bottom shunts or a nearby converter do not dominate one temperature reading. Allow for lag between package junction, copper and thermistor when setting protection thresholds.

## 15. CAN interface

**U801, D801, J801/J802, termination R802/JP801.**

- Place protection at the cable entry and U801 nearby. Keep CANH/CANL paired, with similar geometry and a short branch from the bus path to the transceiver.
- For two pass-through connectors, maintain a short continuous bus path and minimise the transceiver/termination stub. Put selectable termination near that path and retain access to JP801.
- Provide short, broad ESD return connections. Keep CAN_SHIELD/drain separate as drawn; do not accidentally merge it into GND by a mounting hole or copper pour.
- Place transceiver decoupling at the supply pins. Keep standby pull-up near U801; route TX/RX/STB over ground and away from the inverter.
- Review trace impedance/geometry for the selected CAN-FD rate and cable arrangement; avoid long stubs. A 120 Ω termination value is not a reason to serpentine a short on-board pair.

## 16. USB-C service connector and CP2102N

**J201, U202, U901 and local supply/VBUS components.**

- Put ESD protection adjacent to USB-C so the pair encounters protection before entering the board. Keep the discharge return short and out of the crystal/ADC region.
- Join duplicated USB-C D+/D− contacts with minimal stubs, then route a **90 Ω differential target** using the actual 2 oz stackup and fabrication calculator.
- Keep pair geometry consistent and routes reasonably matched, over continuous ground. Avoid layer changes; if necessary, transition both together with nearby ground-return vias. Do not cross plane voids or route next to phase copper.
- Place U901 near the connector/protection, with its decoupling and VBUS detection divider local. Keep UART source paths short and separate from high-current power input routing.
- Keep CC resistors local to the connector and preserve the service-only USB power configuration. USB shield/C207 remains the separate optional coupling network in the schematic.
- Check connector shell pads, edge overhang, insertion force, cable clearance and solder inspection access on both sides. Do not let a screw or enclosure silently bypass the intended shield connection.

## 17. SWD, buttons, LEDs and test access

- Put J1001 where a keyed cable can be attached with the heatsink installed. Mark pin 1; VTREF is sense-only. Keep SWCLK/SWDIO short, referenced to ground and away from gate/phase routing.
- Place reset/boot buttons where they can be operated safely during bench work. Keep their pin-local pulls near U301 and avoid long antenna-like traces on reset/boot nets.
- Keep LEDs visible and their switching currents out of VREF/ADC ground branches.
- Provide accessible test points for VM/GND, both 5 V sources, 5V_SYS, 3V3, VCC, current-amplifier outputs, VBUS_SENSE, brake command and reset. Place a nearby ground pad for low-voltage probing.
- Give high-voltage and switching test points suitable spacing and clear labels. Avoid exposed probes near the rotating magnet or heatsink. Do not add long stubs to PB8, crystal, gate or Kelvin input nets merely for test convenience.

## 18. Routing workflow and acceptance checks

### A. Before placement is frozen

- [ ] Fix outline, mounting, magnet position, heatsink/insulation and both-side height envelopes.
- [ ] Record the fixed 2/0.5/0.5/2 oz stack, dielectric geometry, assembly assumptions and via treatment; use section 19 without an external validation gate.
- [ ] Confirm square outline ≤150 × 150 mm, centred bottom encoder, top MCU/MOSFETs and nonoverlapping underside MCU/sensor regions.
- [ ] Establish net classes: motor force/power, switch nodes, gates/bootstrap, Kelvin analog, low-voltage analog, logic and USB differential. Set manufacturing minima separately from current/voltage design rules.
- [ ] Define operational/transient clearance requirements; size power copper/via arrays from current and thermal calculations, not generic track defaults.
- [ ] Place one complete phase cell and review its top/bottom current loop before replicating it.
- [ ] Reserve the underside MCU analog region and converter keepouts; inspect pad-net mappings for live thermal lands.

### B. Routing order

1. Bridge ceramics, shunt force connections and gate/bootstrap loops.
2. Kelvin pairs and pin-local analog/decoupling networks; adjust placement if these cannot be short and quiet.
3. VM/phase/GND distribution, brake loop and thermal copper, preserving the reserved quiet corridors.
4. Both buck converters, mux/LDO, reference distribution and voltage/temperature filters.
5. Encoder ABI/mux, SPI, USB, CAN, SWD and remaining control signals.
6. Ground stitching, test access and silkscreen; refill all zones and inspect every layer.

### C. Before fabrication outputs

- [ ] ERC and PCB DRC pass; no unconnected pads, accidental shunt bypasses, orphan copper or unexplained exclusions.
- [ ] Manually trace each commutation loop, gate return, Kelvin pair and converter feedback path; DRC cannot prove these are good.
- [ ] Check both ground planes for slots created by via arrays, keepouts and power antipads; verify reference continuity for both outer layers.
- [ ] Verify force-path losses, via/connector temperature, shunt heating, LDO thermal budget and heatsink insulation with documented assumptions.
- [ ] Verify footprints and actual orderable packages, all pad/thermal-net assignments, bottom-side mirroring, soldermask, paste and assembly clearances.
- [ ] Inspect 3D/mechanical fit including underside parts, magnet, mating cables, screws and heatsink; mark unverified generic model dimensions.
- [ ] Review BOM/CPL rotations and double-sided assembly process, fiducials and test-fixture access; keep DNP options identifiable.
- [ ] Export and independently inspect Gerbers, drill files and assembly drawings. Check exported dimensions, layer assignments and impedance calculations against the intended rules; external manufacturer validation and stock checks are excluded.

### D. Hardware evidence needed after assembly

Measure low-voltage supplies and power switchover first, then current-sense offset/noise, gate waveforms, bus overshoot and protection/braking at controlled energy. Raise current progressively while checking MOSFETs, vias, shunts, connectors and bulk-capacitor temperatures/ripple. Record any required gate/snubber/filter changes in the schematic as well as the PCB.

## 19. DRC setup and saved layout rules

This is the rule sheet to use when setting up KiCad Board Setup. **All dimensions below are mm.** The supplied screenshots are the source of the manufacturing values; no new fabricator validation or part-availability check is required. Values labelled **project choice** are design margins, not quoted capabilities. These settings are documented here; this Markdown edit does not apply them to a PCB file or claim a DRC pass.

### 19.1 Screenshot limits retained for reference

| Item | Supplied value | Interpretation for this board |
|---|---|---|
| 2 oz multilayer track width / spacing | 0.15 / 0.15 | Use the screenshot's **multilayer** row. Its 0.16 / 0.16 row is for two-layer boards. |
| Multilayer minimum drilled hole | 0.15 | Available limit, not the routine drill choice. Screenshot notes added cost at 0.15. |
| Minimum via drill / copper diameter | 0.15 / 0.25 | 0.05 radial annulus; avoid this absolute minimum in normal layout. |
| Preferred minimum via drill | 0.20 | Screenshot also prefers diameter at least 0.15 larger than drill. |
| Via cost note | 0.20/0.25 drill with diameter below 0.45 costs more | Use 0.45 diameter or larger for ordinary small vias. |
| Via hole-to-hole spacing | 0.20 | Treat as drilled-hole edge-to-edge spacing, not centre pitch. |
| Through-hole pad hole-to-hole spacing | 0.45 | Keep separate from the via-to-via limit. |
| Through-hole size tolerance | +0.13 / −0.08 | Account for fit of connector leads; this is not a track-clearance setting. |
| Press-fit hole tolerance | ±0.05 with stated process restrictions | No press-fit fit specification is assumed for this board. |
| Drilling upper size | 6.3 | Screenshot states holes at/above 6.3 are routed. Prefer simple round mounting holes below this boundary. |

Evidence: user screenshots dated 2026-09-16 at 23:53:32 (drilling), 23:54:15 (vias), 23:54:32 (hole spacing), and 23:54:58 (tracks). Those images do not specify dielectric thickness, soldermask web, soldermask registration or copper-to-edge clearance; the choices below must not be attributed to them.

### 19.2 Board Setup → Design Rules → Constraints

| Setting | Saved project baseline | Basis / use |
|---|---|---|
| Minimum copper clearance | **0.15** | Screenshot 2 oz multilayer floor; use larger class clearances below. |
| Minimum track width | **0.15** | Fine-pitch escapes only; default signal width 0.25. Apply same conservative floor to inner copper features even though inner layers are 0.5 oz planes. |
| Minimum connection width | **0.15** | Project choice to catch narrow zone slivers; does not size power necks. |
| Minimum through-via diameter | **0.45** | Project choice above absolute capability limit. |
| Minimum through-hole/via drill | **0.20** | Preferred drill from screenshot; ordinary via 0.30 drill. |
| Minimum via annular width | **0.10 radial** | Project choice. Check `(diameter − drill)/2`; both presets below comply. |
| Minimum hole-to-hole clearance | **0.20** | Via-to-via base floor. Add 0.45 for pairs involving through-hole component pads, as below. |
| Copper-to-hole clearance (non-connected copper) | **0.25** | Project choice; plated-pad copper intentionally attached to its own hole is exempt. |
| Copper-to-board-edge clearance | **0.50** | Project choice for routed rounded-square edges; no V-score assumption. |
| Silkscreen minimum text height / stroke | **1.0 / 0.15** | Project readability choice. |
| Silkscreen clearance to exposed pads | **0.20** | Project choice; keep polarity/reference markings legible. |
| Blind/buried vias and microvias | **Do not use** | Through-via-only baseline. |

- Set a pair-specific hole-clearance rule of **0.45** whenever either drilled item is a through-hole component pad; retain **0.20** for via–via pairs. This conservatively covers mixed pad–via pairs too. If pair-specific rules are not implemented, use a global 0.45 rule until they are; do not silently accept 0.20 between component holes.
- For equal 0.30 drills, a 0.20 edge spacing needs at least **0.50 centre pitch**. Copper clearance between different-net via pads can require a larger pitch: 0.60 pads at 0.20 copper clearance need **0.80 centre pitch**. Apply the stricter rule.
- Standard through-via preset: **0.60 diameter / 0.30 drill**. Compact fanout preset: **0.45 / 0.20**. Power arrays use calculated numbers of suitably sized vias; neither preset has an assumed current rating.
- Existing footprint-embedded thermal vias must be checked against these rules. A smaller legacy via is a discrepancy to resolve, not a reason to lower the whole-board baseline. Any footprint-specific exception must identify the pad, geometry and reason explicitly.
- Retain footprint-specific paste segmentation and pad geometry. Start ordinary soldermask expansion at **0.05 per side** and minimum mask web at **0.10** as project choices; inspect fine-pitch/QFN packages individually and record any intentional merged opening or local override. Do not resize electrical lands just to satisfy a generic mask preference.

### 19.3 Net classes and routing presets

Global minima are manufacturing floors; net classes below express intended routing. Pad escapes may need local rules, but long routes should return to their class width immediately after escape.

| Class | Track-width preset | Different-net clearance | Additional requirement |
|---|---|---|---|
| Default logic / SWD / SPI / UART | **0.25** | **0.20** | Short pin escape may use 0.15 width/clearance locally. |
| Kelvin sense / ADC / reference | **0.20** | **0.20** | Paired quiet routing; target ≥1.0 separation from switching copper where space allows. |
| Gate drive | **0.40** | **0.20** | Short resistor-to-gate route; larger clearance to unrelated switching/power nets below. |
| Low-voltage 3V3 / 5V / VCC | **0.50** initial preset | **0.20** | Widen for actual branch load and drop; pin-local decoupling loop takes priority. |
| VM / OUT1–3 / BRK_SW / BOOT1–3 | **Pours or purpose-sized tracks** | **0.50 target to unrelated nets** | Project noise/spacing target; narrow package-local gaps need documented local rules ≥0.15. BOOT floats with OUT; use actual voltage difference when judging insulation. |
| Shunt force / bridge GND return | **Calculated pours, no default current width** | **0.20 floor; 0.50 to unrelated control copper preferred** | Do not reclassify all GND as a special current route; use local geometry/rule areas and manual loop review. |
| CANH/CANL | **0.25 initial routing preset** | **0.20** | Paired short routing; preserve bus topology and termination. |
| USB D+/D− | **Impedance-derived width and gap** | **0.20 to other nets; 0.15 absolute interpair-gap floor** | 90 Ω differential target; use actual dielectric geometry and 2 oz copper. |

- The 0.50 power-net target is a project layout margin, **not an isolation certification or a claim that every package has that pin spacing**. Keep wider spacing outside package escapes and around probe/connector areas.
- USB width/gap cannot be honestly fixed from copper weight alone. Save calculated values once the dielectric stack is entered; retain ≥0.15 track width/gap. If 90 Ω cannot be achieved within those limits, adjust dielectric geometry/routing geometry rather than assuming 0.15/0.15 produces 90 Ω.
- Use **≤0.50 USB intra-pair length mismatch** as a conservative project routing target, with matched via count and no deliberate stubs. This is a project choice, not a quoted protocol maximum. Avoid unnecessary meanders on an already short pair.
- Make local higher-clearance rule areas around the encoder, ADC networks, crystal and switching islands where useful. DRC copper clearance alone cannot detect magnetic interference or a poor return path.

### 19.4 Mechanical and connectivity checks

- Six enabled copper layers with **2 / 0.5 / 0.5 / 0.5 / 0.5 / 2 oz**; L2/L5 assigned GND, L3 signals and L4 power.
- Edge.Cuts forms one closed, non-self-intersecting rounded square with equal width/height and maximum **150 × 150** bounding dimensions. Corner radius is chosen with the final mechanics; 5 is the starting preference.
- U601 is on B.Cu with its sensing centre at the outline centre; U301 and Q401–Q403 are on F.Cu. Treat these as explicit placement checks, not capabilities of generic electrical DRC.
- MCU underside component courtyards must not overlap the encoder/magnet envelope. Courtyard checks work per side; separately check through-board height, magnet and heatsink envelopes in the mechanical view.
- Enable shorts, clearance, minimum width, annular ring, drill spacing, edge clearance, courtyard overlap, unconnected items and schematic/PCB parity checks. Review rather than globally suppress footprint-library differences for deliberate local custom footprints.
- Refill zones before every final DRC run. Resolve every error and triage warnings individually; save a report with any narrowly justified exceptions.
- Inspect source-side force vias on all six layers: **no GND connection before the shunt**. Check that sense pads use their dedicated traces and never join force pours. These are mandatory manual checks even if the netlist/DRC is clean.
- This stage does not run sourcing checks or request fabrication/assembly sign-off. It still checks the design's own dimensions, connectivity, current paths and exported artwork.

## 20. Source and interpretation notes

The reference designators, values and net distinctions above come from the current local schematic, BOM and linked release documents. Placement choices such as two inner ground planes and underside analog grouping are this board's engineering plan; they are not claims that a manufacturer has approved this board. Linked manufacturer guidance supplies package/converter/interface constraints. Where a manufacturer document conflicts with a generic placement preference, resolve the specific device requirement before routing that block.

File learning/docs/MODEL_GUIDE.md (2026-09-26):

# Model guide: equations, topology and limits

## Read this as a modelling contract

The models explain consequences and compare choices. They do not include a routed PCB extraction, measured motor, measured capacitor bias curve, MOSFET vendor switching model, regulator control loop or complete FOC controller. They should not be used to declare the board fabrication-ready.

All Python functions use SI units. Browser controls display engineering units and convert to SI. The browser runs without network requests.

## A. Half-bridge winding model

Topology: an ideal synchronous half bridge switches a node between 0 and V. A series R–L–back-EMF load connects that node to the fixed reference. This is a buck-equivalent teaching circuit, not a literal isolated phase of a floating-neutral motor.

For switch state q:

`di/dt = (qV − Ri − E)/L`.

For a constant q over Δt:

`i(t+Δt) = i∞ + (i(t)−i∞)exp(−ΔtR/L)`, with `i∞=(qV−E)/R`.

The implementation solves the fixed point across ON and OFF intervals, so plots start in periodic steady state. It sets `E = DV − RĪ` to obtain the requested mean current. This is not a speed trajectory or current-controller simulation. Source current for the capacitor teaching waveform is set to mean bridge current.

The first static plot and lab default use 36 V, D=0.5, 20 kHz, R=0.1 Ω, L=100 µH and Ī=20 A. Deadtime, diode recovery, nonlinear inductance and semiconductor losses are excluded.

## B. Constant-current PWM charge model

Assumptions: winding current I is constant, source current is DI, switch draws I for DT and zero for (1−D)T.

Capacitor current, positive into capacitor:

- ON: `icap = −(1−D)I`.
- OFF: `icap = DI`.

Therefore:

`ΔVcap,pp = ID(1−D)/(fC)`

`Icap,rms = I sqrt(D(1−D))`

`PESR = Icap,rms² RESR`.

The terminal voltage adds `RESR icap`. A switching change makes an ESR step of magnitude `I RESR`. ESL is deliberately excluded from this ideal discontinuous-current time plot: an instantaneous current step through an inductor would imply an impulse. Use finite edge time and the separate frequency/placement models for high-frequency behaviour.

These formulas are not applied directly as a three-phase capacitor rating.

## C. Frequency-domain supply network

The ideal voltage source is reached through `Zs = Rs + sLs`. Each capacitor branch has:

`Zk = Rk + sLk + 1/(sCk)`.

The board sees:

`Zbus = 1 / (1/Zs + Σ1/Zk)`.

Load-current disturbance transfer: `δVbus/δIload = −Zbus`.

Source-voltage disturbance transfer: `δVbus/δVs = Zparallel_caps/(Zs + Zparallel_caps)`.

These are different transfer functions. The plotted impedance phase is the phase of positive Zbus; the minus sign in the load-disturbance relationship adds inversion.

### Assumed branches in the comparison

| Branch | C | ESR used | Series L used |
|---|---:|---:|---:|
| Three existing bulk cans, lumped | 2,040 µF | 10 mΩ combined | 23 nH combined |
| Existing selected local bypasses, lumped | 7.81 µF nominal × 0.5 | 5 mΩ | 3 nH |
| N study ceramics | N × 4.7 µF × 0.5 | 20 mΩ/N + 1 mΩ common | 1 nH/N + 3 nH common |
| Optional external 1,000 µF | 1,000 µF | 30 mΩ | 30 nH |

Only the existing nominal capacitance values come from the schematic. Parasitics and retention in this table are modelling assumptions, not exact datasheet values. The selected local bypasses are C104–106 plus C412/C422/C432. Auxiliary converter inputs and 10 nF source-above-shunt bypasses are excluded. This model does not capture their additional impedance modes.

The N ceramics are treated as equally connected parallel parts. There is no geometric extraction or unequal-sharing model. Thermal predictions stop at resistive power; no temperature is inferred.

## D. Three-phase periodic switching comparison

For phases k with offsets θk = 0, 2π/3, 4π/3:

`dk(t) = 0.5 + 0.5 m cos(ωe t − θk)`

`ik(t) = sqrt(2) Irms cos(ωe t − θk − φ)`

`qk = 1` when the common triangular carrier is below dk, otherwise 0.

`Iload = Σqk ik`.

Default: 20 kHz centre-aligned sinusoidal PWM, 250 Hz electrical frequency, m=0.8, φ=30° and 40 Arms phase current. One electrical period contains 80 PWM periods. We sample 512 times per PWM period, then repeat with 1,024 for a resolution check. Sampling rates are 10.24 and 20.48 MHz respectively.

A first-order 80 ns time-constant filter smooths ideal bus-current edges using an exact sampled recurrence. This avoids artificial undershoot from a truncated continuous filter spectrum. It is an explicit numerical/physical approximation, not a MOSFET model or a stated 80 ns rise time. A first-order 10–90% rise time is about 2.2τ. The phase currents themselves are prescribed sinusoids without winding PWM ripple or feedback from bus ripple.

The FFT of that current excites the passive network independently at each nonzero frequency:

`Vbus(f) = −Zbus(f) Iload(f)`.

The DC bus voltage is `Vs − Rs mean(Iload)`. Capacitor branch current is `Vbus(f)/Zk(f)`, positive into each capacitor. Source current follows KCL. An inverse FFT reconstructs periodic steady-state waveforms. No startup transient is present in this calculation.

The analytical expected mean bus current is:

`Imean = (3/4)m sqrt(2) Irms cosφ ≈ 29.394 A`.

The numerical result differs by less than 0.01%. At DC, capacitor branch currents are zero. Charge balance and KCL are checked. The two representative p-p voltage results change by about 0.74% and 1.10% when time resolution doubles.

### What this can and cannot conclude

It can show current sharing, resonance and relative behaviour under the stated waveform. It cannot claim a final bank count or controller stability. Large predicted bus movement makes the prescribed-current approximation less credible because the real inverter/current controller would respond. This is especially relevant to the 20-ceramic scenario's large variation. Even a small numerical discretisation error does not mean a small physical modelling error.

Distributed three-phase layout has several bus nodes and coupled loops; collapsing them to one node loses spatial information. Changing modulation, power factor, electrical frequency, source impedance, temperature or capacitor retention can change the ranking.

## E. Load-step and connection model

This model uses one capacitor with ESR but no ESL. States are cable current is and ideal capacitor voltage vc. The load draws il.

`vbus = vc + Rc(is − il)`

`Ls dis/dt = Vs − Rs is − vbus`

`C dvc/dt = is − il`.

State matrix:

```text
A = [ −(Rs+Rc)/Ls    −1/Ls ]
    [     1/C          0   ]

B = [ 1/Ls    Rc/Ls ]   inputs [Vs, il]
    [   0     −1/C  ]
```

The Python reference uses SciPy's continuous linear state-space response. The browser independently evaluates the exact 2×2 matrix exponential, including underdamped, overdamped and critically damped cases. There is no Euler integration instability hidden behind the sliders.

Load-step initial conditions: vc=Vs, is=0, then il=20 A.

Connection initial conditions: vc=0, is=0, il=0, then an ideal Vs is connected.

With capacitor ESR, the source-voltage transfer is:

`H(s) = (1+sRcC)/(1+sC(Rs+Rc)+s²LsC)`.

Natural frequency `f0 = 1/(2πsqrt(LsC))` and damping `ζ = (Rs+Rc)sqrt(C/Ls)/2` describe the denominator. The numerator zero affects the observed voltage response. Source-current and capacitor-voltage peaks need not occur together.

Missing: source current limit, diode clamps, precharge, TVS nonlinearity, brake control, voltage-dependent ceramic capacitance, contact bounce, and converter dynamics. Use it to understand the plant and initial conditions, not to approve a connection method.

## F. Braking-energy calculation

For constant C, `ΔE = ½C(V2²−V1²)`. Solving for required C gives `2E/(V2²−V1²)`; solving for final voltage gives `sqrt(V1²+2E/C)`.

The live energy calculator uses 42 to 46 V as an illustrative window independent of the supply model's voltage slider. It models all selected energy reaching the bus and none going elsewhere. Real motor/copper losses reduce returned energy; other loads and charging acceptance change the result. Gravity or externally driven motion can add more energy.

For nonlinear ceramic capacitance, energy change is `∫ v Cdiff(v) dv`, not generally `½ Csmall-signal(V) V²`. The simple fixed-C examples should not be used for a large-signal MLCC energy claim.

## G. Sensing, filters and delay

The fitted resistor network produces nominal gain 28 with 1.65 V bias. Shunts are 0.5 mΩ. The ideal ADC conversion uses 3.3 V/4096, then divides by 0.014 V/A. Resolution is not accuracy.

For a simple hypothetical RC: `H=1/(1+sRC)`. Delay contributes `e^(−sTd)`, with phase `−ωTd` radians. The lab reports their sum at a chosen evaluation frequency, not a calculated closed-loop phase margin.

Actual bus filter: ratio 1/21, and τ=`((540k || 27k)+1k)10nF`. The plotted gain is normalised to DC, so it does not include the constant divider attenuation. Mux on-resistance, ADC acquisition and leakage are excluded.

### Optional feedback capacitor is not a simple differential RC

For one phase, with Rinput=1 kΩ, Rfeedback=28 kΩ, and two 56 kΩ positive-input bias resistors, the positive input's small-signal coefficient from sense-plus is 28/29. If Cf=47 pF is fitted, `Zf=28k/(1+s28kCf)`.

With sense-minus fixed and VREF AC-grounded:

`Hplus(s) = (28/29)[1 + 28/(1+s28kCf)]`.

It has DC gain 28 and high-frequency gain 28/29. Divide by 28 for the normalised plotted response. The sense-minus path is `−28/(1+s28kCf)`, so the two paths no longer cancel common-mode input identically at high frequency. These capacitors are DNP in the actual schematic. Finite op-amp gain/bandwidth and parasitic capacitance are omitted.

The ringing/sampling illustration is synthetic: a known sinusoidal current plus decaying 2 MHz artifacts at chosen edge times. It teaches timing, and is not represented as a simulated or measured amplifier output.

## H. Gate-drive and local-decoupling estimates

Gate experiment assumptions: 10 V drive, 4 V Miller plateau, 12 nC Miller charge and 3 Ω combined driver/internal resistance. External gate resistance is adjustable. `Igate=(10−4)/(Rext+3)` and `tedge=Qgd/Igate`. None of those assumed switching parameters is a characterised value for our assembled CSD88599 stage.

Overlap loss: `½VI(tr+tf)f`, per hard-switched MOSFET with equal estimated tr and tf. Do not multiply by six and treat it as a complete inverter loss model; device conduction states and additional loss terms differ.

The separate inductance spike estimate uses an independently selected current transition time. Gate-voltage slew and commutating-current slew are not interchangeable, so these controls are deliberately not forced to agree.

## I. Validation scope

See [validation notes](../qa/VALIDATION.md). Models are checked against independent identities, conservation, a finer sampling grid and a separate Python/JavaScript transient implementation. Their physical assumptions remain the dominant limitation.

The installed LTspice batch attempt did not produce successful results. The lesson calculations therefore use the documented numerical models; no successful SPICE verification is claimed. Automated schematic detections were not promoted to electrical findings without manual connectivity checks.

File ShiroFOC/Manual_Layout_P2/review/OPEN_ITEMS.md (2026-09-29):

# P2 starting-layout checks and open items

This is an unrouted placement handoff, not a fabrication release. The native reports are `erc.json` and `drc.json`; the cross-check is `validation.json`.

## Passed

- Native schematic ERC: 0 violations.
- All 260 schematic components have their assigned footprints in the PCB.
- Every represented electrical pad matches the exported schematic net; no unexpected missing components.
- Original P1 board and checked Manual_Rebuild source files remain unchanged (SHA-256 comparison).
- No component courtyard overlaps reported. No board tracks, vias or copper zones have been added. Footprint-integrated holes and keepouts remain.
- The imported DMM0022A copper bars now belong to their existing power-pad nets; their geometry was retained. This change is local to this new project.

## Resolve during layout / before fabrication

| Item | Evidence | Action |
|---|---|---|
| U204 / TLV755 imported land pattern | Four copper clearance errors: 0.10 mm between its GND land and neighbouring lands | Review/replace the land pattern against the actual package drawing. This is below the saved 0.15 mm board minimum; do not simply suppress it. |
| U901 / USB bridge thermal vias | Four hole-web errors: 0.15 mm vs the 0.20 mm local minimum | Adjust the thermal-via pattern or select a suitable verified land pattern before routing this area. |
| U205 symbol pins 19/20 | Two native schematic-parity warnings: no matching pads in the imported footprint | These are the symbol's NC/test pins. Retain the recorded exception only after confirming the exact module package; do not invent copper pads just to clear parity. |
| Imported silkscreen | 19 warnings: four edge clips, seven over exposed copper, eight overlaps | Clean silkscreen after placement is settled. Some imported text such as `Designator9` is library clutter. |
| R7 comparison shunt | Disconnected, DNP and off-board | Remove it before production exports; DNP does not remove Gerber copper or paste. |
| Rough placement | Bootstrap/gate/ADC/decoupling loops are not routed or optimized | Adjust these parts at their actual pins as you route; use the README checklist. |

The 499 unconnected items are expected at this stage. They are not a count of complete nets. Final DRC also requires connected ground planes, intentional current paths and completed routing.

No component-stock or fabricator-capability validation was performed. Prior firmware/protection, cooling/current-rating and LR2512D assembly-profile questions remain in scope for the final design review, not evidence of completed qualification here.

## File notes

The scripts in this folder record the migration, not a production build system. They depend on the original projects and the local `/tmp/cascade_work/edit.py` helper and should not be rerun on a manually edited PCB. Work in the native project files instead. `placement_manifest.json` records the initial placement; C1 and C5 were subsequently moved 0.15 mm left to meet the saved power clearance.

The optional brake NTC addition is documented in [brake_ntc/README.md](brake_ntc/README.md); it adds no new DRC findings. The current reports include this addition.

Latest update: [bootstrap return correction](bootstrap_return/README.md). Current DRC has 34 findings from the latest user placement, with no additions from the return-net correction; the NTC annotation issue is repaired.

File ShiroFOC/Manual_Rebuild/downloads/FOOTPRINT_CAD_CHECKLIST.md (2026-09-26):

# Current footprint and CAD checklist

**BVR comparison option:** R7 is a disconnected, DNP BVR-Z-R0005-1.0 with its BVR4026 footprint, excluded from the BOM but available for PCB placement comparison. Keep it off-board and remove before production exports. R1/R3/R5 remain the active LR2512D shunts.

Updated 26 September 2026 after implementing the accepted review changes.

**255 schematic components including one DNP comparison shunt; zero native ERC violations.** U604 (TPS2553DBVR) is newly added; its footprint/3D association is intentionally deferred to the final CAD pass. All previously assigned footprints are retained. [Implementation / selections / limits](../review/schematic_review_2026-09-26/implementation/README.md) · [Current component catalogue](component_footprint_map.csv).

## Model policy — updated 26 September 2026

User accepts generic 3D models; exact vendor STEP downloads are no longer required. Retain suitable existing models and use generic package models where available, with approximate geometry clearly identified. Footprint dimensions, pad numbering and symbol-to-pad mapping still require verification. This policy does not itself assign missing models or complete the final footprint pass. No CAD downloads are currently requested from the user.

**Implemented:** R1/R3/R5 now use Milliohm **LR2512D-3W-0.5mR-1% (C500733)** with `Manual:R_Shunt_LR2512D_0m5_3W_Kelvin`. The two-terminal part has four PCB connection pads: power1/4, sense2/3; net-tie groups1-2 and3-4. Manufacturer main lands plus user-requested horizontal sense stubs; no downward legs. Generic2512 model. [Dimensions, routing rules and native validation](../review/kelvin_shunt/README.md). No BVR download required.

## Optional exact models — reference only, no download required

Put original ZIPs in `downloads/incoming/`. Look for an actual `.step` or `.stp` file. Our functional schematic symbols remain in place.

| Part | References | What to download |
|---|---|---|
| **AMASS XT60PW-M** | J101 | Exact right-angle PCB-mount **PW-M** STEP, not a cable or vertical XT60. Footprint exists. |
| **HRO TYPE-C-31-M-12** | J201 | Exact USB-C receptacle STEP. Footprint exists; shell/board mounting geometry varies between models. |
| **Silicon Labs CP2102N-A02-GQFN20** | U901 | **QFN-20, 3 × 3 mm** STEP; not 24/28-pin versions. Electrical footprint exists. |
| **Kyocera CX3225FB24000C0FZZH1** — optional exact model | Y301 | Search this exact MPN for a KiCad/STEP bundle. **24 MHz, 7 pF, 3.2 × 2.5 × 0.7 mm.** Manufacturer lands already match the assigned standard footprint; a generic STEP exists. Exact STEP availability is unconfirmed, so this does not block placement. [Exact datasheet](https://ele.kyocera.com/assets/products/crystal-device/specification/CX3225FB_7pF.pdf). |

Models are useful for mechanical checking; missing exact purchased-part STEP models do not prevent electrical routing.

Optional: Panasonic **EEVFK1J681M** exact STEP for C101–C103. Existing conservative Ø18 × 17.5 mm model differs from the nominal Ø18 × 16.5 mm body. The Panasonic K16 lands were checked previously. J1/J501 are plated solder-wire features; no purchased connector model is needed for them.

## New item for the final CAD pass

**U604: TPS2553DBVR**, TI DBV SOT-23-6, constant-current version (not TPS2553-1). Associate/verify its footprint and model during the final CAD pass; no download is requested now. C606/C607 retain standard0603 footprints.

## Chosen and assigned — no download required

| Part / refs | Decision |
|---|---|
| CSD88599Q5DC U1–U3 | Imported footprint/STEP retained. Symbol range pins expanded; thermal vias renamed to VIN pad27; NC pads retained. Pad-net fixture passed. |
| Motor terminals J1 | Earlier three large solder-wire holes: `Connector_Wire:SolderWire-6sqmm_1x03_P14mm_D3.5mm_OD7mm`. Actual installed drill **4.4 mm**, copper7mm, pitch14mm. |
| SN74LVC3G17DCUR U603 | `Package_SO:VSSOP-8_2.3x2mm_P0.5mm`; standard STEP exists. |
| Sensor selector JP601 | `Jumper:SolderJumper-3_P1.3mm_Open_Pad1.0x1.5mm`. Bridge1–2=3V3 or2–3=5V; never both. Open=no sensor power. |
| C205/C206/C214/C215 | TDK **C3225X7R1E226M250AB**, 22µF25VX7R,1210. |
| C218/C219 | TDK **C3225X7R1C226M250AC**, 22µF16VX7R,1210. |
| R210/R212 | Yageo **RC0603FR-0722KL**,22k1%,0603; mux coarse OV threshold raised. |

Capacitor selection uses actual manufacturer bias/temperature curves; see the implementation notes for assumptions and the revised 10V output sizing basis. Generic1210 STEP height may differ: selected capacitor bodies are2.5mm nominal, allow2.7mm. No custom capacitor model is needed to start layout.

Already present: STSPIN32G4, LMR36510, TPS2121, TLV755, MPM3620A, Würth47µH inductor, CSD19531, UCC27517A, TLV3012B, AS5047P, TMUX1574, BMI323, TCAN3413, PESD2CANFD24V-T, TPD3E001, USBLC6, JST GH and Samtec SWD. Retain earlier documented family/envelope-model caveats. Ordinary passives, M3 clearance holes and test pads use standard libraries.

MPM NC/test19/20 intentionally have no solder lands; do not restore them from the uncorrected ZIP. JST `MP` pads are mechanical tabs.

## Carry into the next layout / prototype review

- **R6 implemented:** TPS2553 current-limited external sensor supply and PC13 fault input; bench-test supply survival under shorts.
- **R3:** characterize the coarse fast overcurrent trip; normal ADC measurement is unchanged. No precise25A hardware trip claim.
- Check converter startup/load-step behavior and crystal startup/frequency/drive on the prototype.
- Confirm SW301 exact TL3305A actuator height if enclosure clearance is tight.

No stock or fabricator validation. The existing draft PCB has not been synchronized or routed as part of these schematic changes.

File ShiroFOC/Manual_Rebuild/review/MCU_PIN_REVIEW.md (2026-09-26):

> **Interface update, 2026-09-26:** The shared SPI and feedback selection portions below are historical. See the [implemented sensor interface revision](sensor_interface_revision/README.md) for the current dedicated SPI3, IMU I2C2, external-input and MCU pin assignments.

# MCU pin and resource review — manual rebuild

Date: 2026-09-25

## Verdict and scope

No incompatible MCU pin assignment or duplicate physical U4 pin allocation found in the saved schematic. This conclusion requires the firmware configuration below. All 65 package-pad entries occur once in the exported netlist, including the two deliberate NC pins and exposed pad. U4A/B/C/D/E/F represent one physical component.

This is a bounded MCU pin/function and resource review, not PCB release approval. Native KiCad ERC has 16 findings on the root, gate-driver and bridge sheets; none is reported on the MCU sheet. Those findings have not been cleared by this review. ADC timing, crystal startup, analog accuracy, firmware execution, PCB routing and assembly geometry are not validated here. No circuit changes were made.

Evidence: fresh native KiCad XML netlist after saving current editor changes; raw schematic/library review; local STSPIN32G4 DS13630 Rev 2 tables 6/7 (pages 11–14), cross-check of current Rev 3 tables; STM32G431 DS12589 Rev 6 pin descriptions and alternate-function table. Confidence: high for supported pin functions and observed connectivity; conditional for runtime behavior until firmware and bench verification.

## Required firmware choices

1. **Keep TIM1 for the motor bridge.** Its internal PE8–PE13 connections drive the three complementary gate pairs. PE7 controls WAKE; PE14/PE15 receive READY/NFAULT. PC8/PC9 are the internal I2C3 driver connection. Reserve all these resources. Configure fault/break response and dead time deliberately.
2. **Use TIM4 for feedback and TIM17_CH1 for PB9 brake PWM.** PB9 also offers TIM4_CH4, but TIM4's counter is already needed for encoder/Hall processing. In quadrature mode use PB6/PB7 as A/B; handle PB8 index explicitly, for example using EXTI8. In Hall mode configure the three TIM4 inputs accordingly. Select one feedback source at a time.
3. **Disable unused USB-C dead-battery pull-downs early:** set PWR_CR3.UCPD1_DBDIS = 1. Otherwise UART levels on PA9/PA10 can enable 5.1 kΩ internal loads on PB6/PB4, which this board uses for feedback A and SPI MISO. This is extra loading, not proof those signals necessarily fail.
4. **Use SWD only.** PA13/PA14 remain debug pins; explicitly configure PB3/PB4 for SPI3 and PA15 for chip select. Full JTAG/SWO would compete with these signals.
5. **PB8 is also BOOT0.** R305 keeps the feedback mux disabled in reset; R307 holds PB8 low. The BOOT button raises PB8 through R1001. Verify boot option bytes allow the intended button behavior. Use this button for reset/boot, not during active feedback operation. Keep PG10 configured as NRST.
6. **Use GPIO chip selects / software NSS for SPI3.** PA15 selects AS5047P; PC4 selects the IMU. Only one selected at a time; configure transfers for each sensor's required protocol. PA4/PA5 remain IMU interrupts (EXTI4/5).
7. **Configure the op-amps for the actual external feedback networks.** Select the VINP/VINM pins listed below; do not silently substitute internal PGA gain. Keep analog pins in analog mode. PA2, PA6 and PB1 expose the outputs to ADC-capable pins. There are two ADCs, not three independent simultaneous converters: the FOC acquisition schedule must account for this and for valid low-side shunt sampling windows. Slow NTC/bus readings must not disrupt current acquisition.
8. **VREF+ is externally supplied here.** Keep the internal VREFBUF output disabled/high impedance. R301/R302 are 0 Ω links, not defined RC filter resistances. VDDA and VREF+ have their own local capacitors.
9. **PC14 is a slow enable output.** Prefer open-drain, low-speed drive with its existing 10 kΩ pull-up. PC13/PC15 spares have restricted drive capability. Do not enable the LSE crystal function while PC14 is used for feedback enable.
10. **Treat PA8 as spare GPIO, not a promised independent PWM output.** Its current label SPARE_TIM_GPIO is too broad; TIM1 is already committed to the motor bridge.
11. **VBUS_SENSE requires the feedback mux to be enabled.** U602 also switches the bus divider. Allow the RC node to settle before using the ADC result.

## Interface map

| Board function | GPIOs | Peripheral/configuration |
|---|---|---|
| CAN TX / RX | PA12 / PA11 | FDCAN1, AF9 |
| CAN standby | PB10 | GPIO output |
| USB bridge TX / RX | PA9 / PA10 | USART1, AF7; bridge RX/TX respectively |
| SPI clock / MISO / MOSI | PB3 / PB4 / PB5 | SPI3, AF6 |
| Encoder / IMU chip select | PA15 / PC4 | Independent GPIO outputs |
| IMU interrupts | PA4 / PA5 | GPIO inputs, EXTI4 / EXTI5 |
| Feedback A / B / I or Hall 1 / 2 / 3 | PB6 / PB7 / PB8 | TIM4 CH1 / CH2 / CH3, AF2; index handling depends on mode |
| Feedback mux enable / select | PC14 / PD2 | GPIO outputs |
| Brake PWM | PB9 | TIM17_CH1, AF1 |
| Bus voltage | PA0 | ADC1 or ADC2 channel 1 |
| Temperature A / B / C | PC3 / PC0 / PC1 | ADC1 or ADC2 channels 9 / 6 / 7 |
| SWD data / clock | PA13 / PA14 | SWD |
| Status LED | PC2 | GPIO, low turns LED on |
| Main crystal | PF0 / PF1 | HSE oscillator |

## Current amplifier pin map

| Phase | Amplifier | + input | − input | Output / external ADC input |
|---|---|---|---|---|
| U | OPAMP1 | PA1, pad 14 | PA3, pad 16 | PA2, pad 15 / ADC1_IN3 |
| V | OPAMP2 | PA7, pad 20 | PC5, pad 22 | PA6, pad 19 / ADC2_IN3 |
| W | OPAMP3 | PB0, pad 23 | PB2, pad 25 | PB1, pad 24 / ADC1_IN12 |

The separate amplifier symbols do not need another wire back to U4A: they already describe analog resources inside the same MCU. Output-to-ADC capability is present on these pins. Two listed outputs share ADC1; simultaneous acquisition of all three is not implied.

## Page walkthrough notes

- C301/C302 provide 100 nF plus 10 µF on 3V3; C307 decouples VBAT. VBAT is the MCU backup-domain supply, connected to 3V3, not the motor battery.
- R301 feeds VDDA with C303/C304 (100 nF / 1 µF). R302 feeds VREF+ with C305/C306 (100 nF / 1 µF). These are direct DC connections with local capacitors, not independent precision supplies.
- Y301 is 24 MHz. C308/C309 are 10 pF each; their series-equivalent load is 5 pF plus board/pin stray capacitance. This is a plausible starting point for the specified 7 pF crystal, not a measured oscillator qualification.
- R303 pulls NRST high; C310 provides local noise filtering; reset buttons pull it low. SW301 and SW1002 are electrically duplicate reset buttons and are optional simplification candidates.
- J1001 carries SWD, target-voltage reference, ground and reset. Its VTREF tells the debugger the target logic voltage; do not assume it powers the board. SWO is intentionally absent.
- R304 limits status LED current; PC2 sinks that current when low.

## Complete observed package allocation

The symbol uses pad 65 for the physical exposed pad. GPIO names on the op-amp units have been expanded below from the manufacturer pin table.

| U4 pad | Pin / function | Saved schematic net |
|---|---|---|
| 1 | REG3V3/VDD | `3V3` |
| 2 | VBAT | `3V3` |
| 3 | PC13 | `/MCU / clock / SWD/SPARE_GPIO_3` |
| 4 | PC14 | `FEEDBACK_ENABLE_N` |
| 5 | PC15 | `/MCU / clock / SWD/SPARE_GPIO_1` |
| 6 | PF0 | `Net-(U4A-PF0)` |
| 7 | PF1 | `Net-(U4A-PF1)` |
| 8 | PG10/NRST | `/MCU / clock / SWD/NRST` |
| 9 | PC0 | `NTC_PHASE_B` |
| 10 | PC1 | `NTC_PHASE_C` |
| 11 | PC2 | `Net-(D301-K)` |
| 12 | PC3 | `NTC_PHASE_A` |
| 13 | PA0 | `VBUS_SENSE` |
| 14 | PA1 / OPAMP1 VINP | `/Current / temperature/OPP_U1` |
| 15 | PA2 / OPAMP1 VOUT | `OPO_U1` |
| 16 | PA3 / OPAMP1 VINM | `/Current / temperature/OPN_U1` |
| 17 | PA4 | `IMU_INT1` |
| 18 | PA5 | `IMU_INT2` |
| 19 | PA6 / OPAMP2 VOUT | `OPO_V1` |
| 20 | PA7 / OPAMP2 VINP | `/Current / temperature/OPP_V1` |
| 21 | PC4 | `IMU_CS_N` |
| 22 | PC5 / OPAMP2 VINM | `/Current / temperature/OPN_V1` |
| 23 | PB0 / OPAMP3 VINP | `/Current / temperature/OPP_W1` |
| 24 | PB1 / OPAMP3 VOUT | `OPO_W1` |
| 25 | PB2 / OPAMP3 VINM | `/Current / temperature/OPN_W1` |
| 26 | VREF+ | `VREF+` |
| 27 | VDDA | `VDDA` |
| 28 | PB10 | `CAN_STB` |
| 29 | GLS1 | `GLS1` |
| 30 | GLS2 | `GLS2` |
| 31 | GLS3 | `GLS3` |
| 32 | PGND | `GND` |
| 33 | NC | `unconnected-(U4C-NC-Pad33)` |
| 34 | NC | `unconnected-(U4C-NC-Pad34)` |
| 35 | BOOTSTRAP3 | `BOOTSTRAP3` |
| 36 | OUT3 | `OUT3` |
| 37 | GHS3 | `GHS3` |
| 38 | BOOTSTRAP2 | `BOOTSTRAP2` |
| 39 | OUT2 | `OUT2` |
| 40 | GHS2 | `GHS2` |
| 41 | BOOTSTRAP1 | `BOOTSTRAP1` |
| 42 | OUT1 | `OUT1` |
| 43 | GHS1 | `GHS1` |
| 44 | PA8 | `/MCU / clock / SWD/SPARE_TIM_GPIO` |
| 45 | PA9 | `USB_UART_TX` |
| 46 | PA10 | `USB_UART_RX` |
| 47 | PA11 | `FDCAN1_RX` |
| 48 | PA12 | `FDCAN1_TX` |
| 49 | PA13/SWDIO | `Net-(U4A-PA13/SWDIO)` |
| 50 | PA14/SWCLK | `Net-(U4A-PA14/SWCLK)` |
| 51 | PA15 | `AS5047P_CS_N` |
| 52 | SCREF | `Net-(U4C-SCREF)` |
| 53 | PD2 | `FEEDBACK_SELECT` |
| 54 | PB3 | `SPI3_SCK_MCU` |
| 55 | PB4 | `SPI3_MISO` |
| 56 | PB5 | `SPI3_MOSI_MCU` |
| 57 | PB6 | `FEEDBACK_A_H1` |
| 58 | PB7 | `FEEDBACK_B_H2` |
| 59 | PB8/BOOT0 | `FEEDBACK_I_H3` |
| 60 | PB9 | `BRAKE_PWM` |
| 61 | VM | `VM` |
| 62 | SW | `Net-(D302-K)` |
| 63 | VCC | `VCC` |
| 64 | REGIN | `3V3` |
| 65 | VSS/EP | `GND` |

## Sources

- [STSPIN32G4 datasheet, DS13630](https://www.st.com/resource/en/datasheet/stspin32g4.pdf), pin list and internal connections. Local copy reviewed: Rev 2; online Rev 3 internal connections cross-checked.
- [STM32G431 datasheet, DS12589 Rev 6](https://www.st.com/resource/en/datasheet/stm32g431cb.pdf), pages 60–66: pin restrictions and AF mapping.

## Snapshot identity

- `MCUclockSWD.kicad_sch` SHA-256: `81fb9d19de067e64c5f2be3e2fce05cd1c92d79f6af38bb857b19683aa1666c0`
- `ShiroFOC_Manual.kicad_sch` SHA-256: `4a075394fe38cbdc4052f12055932860261d23970263e0152ad39fc6f3a98fed`

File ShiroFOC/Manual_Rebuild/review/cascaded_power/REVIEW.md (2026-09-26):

# Cascaded power — MPM3620A revision, 26 September 2026

## Current implementation

```text
VM → U201 LMR36510 + L201 → VCC (10.01 V) → STSPIN and brake gate drivers
                                       └→ U205 MPM3620A → 5V_BAT ┐
USB → existing protection → 5V_USB ──────────────────────────────┤ U203 mux
                                                               └→ 5V_SYS → U204 → 3V3
```

U205 is now **MPM3620AGQV-Z**, replacing TPS82150. The 10 V buck, external STSPIN supply/bypass, source mux, LDO, user's bridge and PCB are unchanged by this replacement. The updated auxiliary sheet is revision **PWR3**. The earlier TPS82150 circuit and review artifacts are preserved in `../../../backups/manual_before_MPM3620A_2026-09-26.zip`.

## Circuit changes

- **R216/R217 = 34.0 kΩ / 6.49 kΩ, 0.1%.** These are MPS Table 1's values for 10 V → 5 V with two 22 µF output capacitors; no feed-forward capacitor is specified. Using the typical 0.798 V reference gives **4.979 V**. Conservative static reference/resistor/input-bias limits give about **4.869–5.089 V**. These bounds exclude transients.
- **C214/C215:** retain two 22 µF / 25 V X7R input capacitors, with at least 10 µF effective total at 10 V.
- **C218/C219:** retain two 22 µF / 16 V X7R output capacitors, with at least 22 µF effective total at 5 V. Exact capacitor MPNs and DC-bias/tolerance/temperature behaviour still need qualification; generic values are not a completed procurement specification.
- **C216 removed.** MPM3620A has internal soft start: typically 1.6 ms from 10% to 90%, specified 0.6–2.6 ms across temperature.
- **R218/R219 = 100 kΩ / 100 kΩ.** R218 pulls U201 PG high from VCC; new R219 pulls the same node toward ground. This retains PG-controlled startup while limiting the direct EN voltage below 6 V. The worst static high bound is about 5.224 V; a conservative loaded nominal calculation gives 4.60 V, comfortably above the 1.65 V maximum rising threshold. PG pulls it low when the 10 V supply is not ready. This does not rely on operating the internal EN clamp.
- **U205 pin 16 = input VCC/10 V.** Its pin **2**, confusingly also called VCC, is the module's **internal 4.9 V output** and is left open. Its capacitor is internal. BST pin 11 also has its capacitor inside and is left open.
- **OUT pins 7/8/9** connect to 5V_BAT. **PGND pins 12/13/14** connect to GND. **SW pins 4/5/6** share the local U205_SW net for the footprint copper; they do not connect to the external output.
- **AGND pin 3** receives only the feedback-divider return on U205_AGND. MPS specifies that AGND joins PGND internally; no external connection is necessary. Route this small return directly to pin 3 and keep power current out of it.
- PG pin 18 is unused. NC pins 10/15/19/20 remain unconnected. Stacked equivalent pins are hidden in the compact functional symbol; all 20 individual pin numbers remain present in the netlist.

The upstream LMR36510 remains a **1 A, 10 V source** shared with gate-drive loads. U205's 2 A rating does not make 2 A available to the complete 5 V rail. The earlier illustrative 320 mA logic load plus 50 mA gate allowance remains about 238 mA at 10 V with assumed 85% conversion efficiency. Existing mux/LDO limits also remain unchanged.

## Imported CAD and necessary corrections

Original supplied ZIP retained: `../../downloads/incoming/ul_MPM3620AGQV-Z.zip`.

- Symbol: `Manual:MPM3620AGQV-Z`, consolidated in `libs/Manual.kicad_sym`. Imported pin numbering checked against MPS page 12. Incorrect imported electrical types were corrected, including ground pins labelled power outputs and VCC labelled power input. Symbol graphics were rearranged to preserve the readable power-flow drawing.
- Footprint: **`Manual:IC18_MPM3620AGQV-Z_MNP`**, from the supplied ZIP. Peripheral pad locations and land shapes were retained.
- Pads **19/20** in the downloaded footprint were inside MPS's underside no-contact region. Their copper, mask and paste were removed; a conservative F.Cu keepout now prohibits tracks, vias, pads and zones in that area. These two NC/test locations deliberately have no PCB solder lands, matching the page 24 recommended land pattern.
- SW and OUT copper bars were converted from unnumbered copper graphics to numbered pads so KiCad can associate them with their nets. The original land outlines, paste and mask are retained within export rounding. The oversized off-courtyard pin marker was replaced with a compact front-silkscreen marker.
- Model: **`libs/3dmodels/MPM3606AGQV.step`**, byte-for-byte from the ZIP. The STEP header names MPM3610GQV; this is a supplier-provided **family package model**, not an exact MPM3620A top marking. Its vertex bounds give **3 × 5 × 1.6 mm**. Offset (−1.5, −2.5, +0.1) mm, unit scale and zero rotation align it with the footprint. Top and angled renders were inspected.
- The superseded local TPS82150 symbol and footprint were removed from the active library; the backup retains them.

## Placement requirements

Place input capacitors directly beside IN/PGND, output capacitors beside OUT/PGND, and the divider beside FB/AGND. Keep FB away from U205_SW. Follow the footprint keepout, connect every PGND pad to substantial ground copper, and provide ground vias nearby. Use only as much SW copper as needed for thermal performance; keep sensitive traces away. Route the gate-drive branch and regulator-input branch separately from the 10 V source, each with its own local bypass. The integrated inductor still produces a switching magnetic field.

## Verification

**PASS, scoped change:**

- Native KiCad netlist export and all 20 U205 pin-to-net checks.
- Every pre-existing pin-to-net association preserved except replacement U205, removed C216 and R217's intentional AGND return.
- **251 components:** C216 removed, R219 added.
- Native ERC: **same 16 pre-existing findings; zero new findings**, no exclusions added.
- PCB and all other schematic sheets have unchanged hashes.
- Isolated footprint test board: **zero geometry/clearance/keepout DRC violations**. Its two unrouted PGND links are expected because this is a footprint fixture, not a routed design.
- ngspice DC divider/enable checks; rendered auxiliary schematic and supplied STEP alignment inspected. SPICE did not model switching-loop dynamics.

This is not a full-board fabrication review. The existing bridge symbol/pad mapping issues and capacitor qualification remain open. No fabrication or availability validation was added. Transients, temperature and EMI still require placed/routed hardware validation.

## Evidence and artifacts

- [MPS datasheet](https://www.monolithicpower.com/en/documentview/productdocument/index/version/2/document_type/Datasheet/lang/en/sku/MPM3620AGQV-Z/document_id/2100/): pages 4–5, 12, 15, 17–20 and 24. Local copy: `../../../DataSheets/MPM3620A.pdf`.
- [Updated overview, power and gate-driver sheets](Power_Revision.pdf)
- [Circuit detail](MPM3620A_circuit.png)
- [Model top](MPM3620A_model_top.png) / [angled](MPM3620A_model_angled.png)
- [Machine verification](validation.json), `netlist_before.xml`, `netlist_after.xml`, `erc_before.json`, `erc_after.json`, `dividers.cir`, `dividers.log`.

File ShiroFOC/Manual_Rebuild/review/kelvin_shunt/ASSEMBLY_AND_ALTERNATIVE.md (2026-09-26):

# Assembly profile and BVR comparison option

R7 is a disconnected Device:R_Shunt symbol using the previous BVR-Z-R0005-1.0 / BVR4026 footprint. All four pins are intentionally marked NC. DNP=true, in_bom=false, on_board=true, exclude_from_sim=true. This allows footprint import for placement comparison without ordering the part. **DNP does not remove copper or paste from fabrication output**: keep R7 off-board while comparing and remove the comparison symbol/footprint before production exports. Active R1/R3/R5 remain LR2512D, unchanged.

## LR2512D assembly question

User-supplied datasheet p3 shows a recommended reflow peak230±5°C and30±10s above220°C; p4 lists a solder-heat resistance test at260±5°C for20±1s, with resistance change limit±0.5%. These are different tests, not an interchangeable recipe. The wave-soldering plot is a separate process and does not apply to ordinary reflow assembly of these SMD shunts.

JLC's published [assembly capabilities](https://jlcpcb.com/capabilities/pcb-assembly-capabilities), checked26September2026, list Standard240±5°C and Economic255±5°C (not adjustable), with double-sided placement listed under Standard. The recommended component reflow peak is not an exact match. Heat-resistance testing makes assembly plausible, but is not confirmation of the actual dwell times or two reflow cycles. Preserve the datasheet with the manufacturing handoff and flag this profile mismatch before ordering; no special process has been requested or confirmed. No stock check performed.

The recipe is normal assembly-process information, not a task for the PCB designer to reproduce manually. It does not by itself require returning to the larger BVR part.

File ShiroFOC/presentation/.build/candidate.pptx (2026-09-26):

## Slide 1

ShiroFOC hardware design

Schematic topology and component decisions

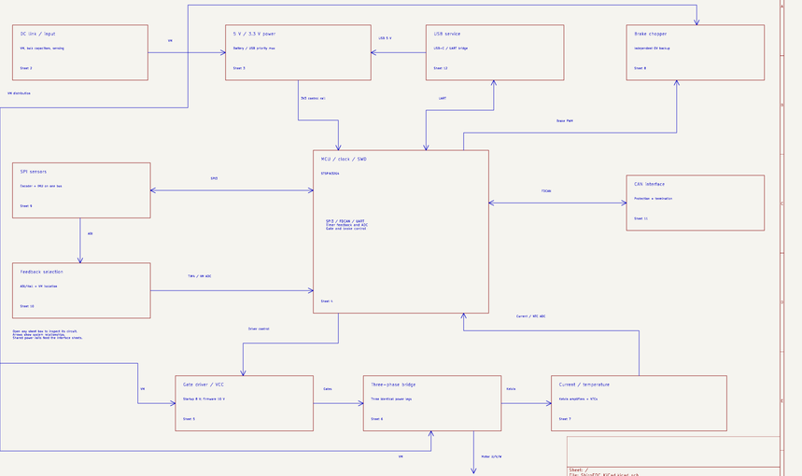
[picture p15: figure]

A single-axis FOC servo module

Topology, component choices and the measurements that establish the operating envelope.

A1 drawing / A0 electrical design

16 September 2026
36 review slides + 5 technical appendices

Prototype targets. Hardware qualification remains open.

KiCad schematic, page 1

01

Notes: ShiroFOC closes motor-control loops locally and communicates with a coordinating motherboard over CAN. This presentation follows the current connected KiCad redraw. It explains the released circuit, documented calculations and engineering tradeoffs. The schematic is ready for first-prototype PCB layout. It is not a fabrication release or a hardware qualification. Current and thermal values remain design targets.

PRIMARY PROJECT SOURCES
ShiroFOC/ShiroFOC_KiCad/outputs/ShiroFOC_Rev_A_Schematic.pdf (A1-Drawing, 16 September 2026)
ShiroFOC/ShiroFOC_KiCad/outputs/ShiroFOC_Rev_A_BOM.csv
ShiroFOC/DESIGN_REVIEW_REV_A.md
ShiroFOC/FIRMWARE_BRINGUP_CONTRACT.md
Values are released schematic/BOM values unless marked as examples. Engineering reasoning beyond recorded intent is interpretation. No hardware qualification is implied.
IMAGE SOURCE: PDF page 1, crop overview.

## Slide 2

Electrical requirements and operating envelope

18–42 V bus

6S–10S packs. The preferred design point is 8S: 29.6 V nominal, 33.6 V fully charged.

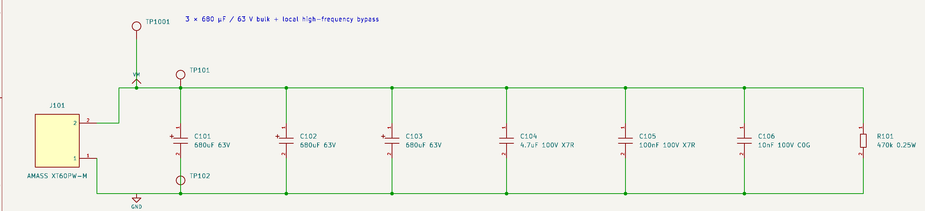
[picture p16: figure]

25 / 40 Arms targets

Passive cooling / a defined thermal solution. Phase current differs from battery current.

80 A peak is a future target

At most 2 s, subject to qualification. Initial +60 A protection prevents treating this as an enabled rating.

60 V MOSFET absolute maximum requires margin for regeneration and switching overshoot.

KiCad schematic, page 2

02

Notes: The design constraints specify 25 Arms free-air, 40 Arms with a defined heatsink or forced airflow, and 80 A peak for no more than two seconds. These refer to motor phase current. They are not demonstrated ratings. An 80 A instantaneous peak cannot be commissioned while a +60 A comparator trip is active. The normal operating bus is approximately 18–42 V, with 10S support conditional on measured switching and braking performance. Capacitor voltage ratings do not raise the permissible MOSFET voltage. Source: DESIGN_CONSTRAINTS.md, Electrical rating target, and DESIGN_REVIEW_REV_A.md, operating envelope.

PRIMARY PROJECT SOURCES
ShiroFOC/ShiroFOC_KiCad/outputs/ShiroFOC_Rev_A_Schematic.pdf (A1-Drawing, 16 September 2026)
ShiroFOC/ShiroFOC_KiCad/outputs/ShiroFOC_Rev_A_BOM.csv
ShiroFOC/DESIGN_REVIEW_REV_A.md
ShiroFOC/FIRMWARE_BRINGUP_CONTRACT.md
Values are released schematic/BOM values unless marked as examples. Engineering reasoning beyond recorded intent is interpretation. No hardware qualification is implied.
IMAGE SOURCE: PDF page 2, crop dc.

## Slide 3

System architecture and FOC signal flow

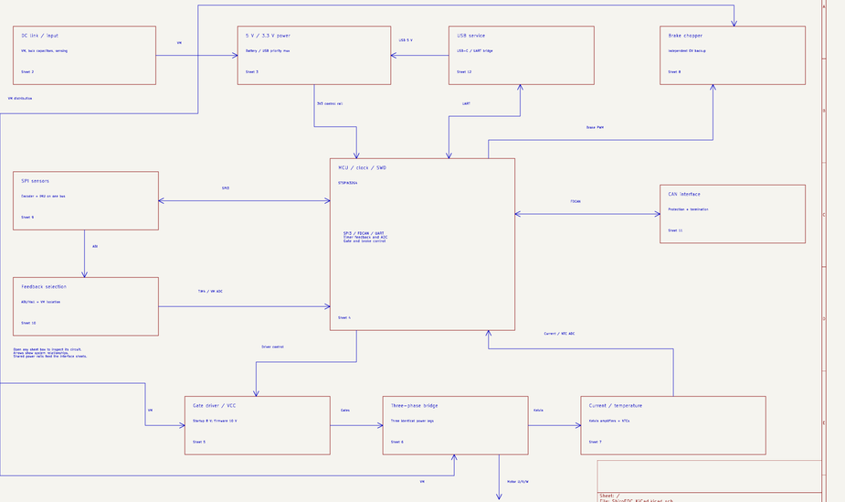
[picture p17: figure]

Local current control

Shunts measure phase current. The MCU uses rotor position and current feedback to calculate PWM.

Outer motion loops

Velocity and position loops set the requested torque-producing current. CAN coordinates modules.

Integrated control, external power

U301 combines the MCU, driver and analog resources. External MOSFETs set power-stage capability.

Position feedback + phase current + synchronized PWM form the local control loop.

KiCad schematic, page 1

03

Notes: Field-oriented control transforms measured phase currents into a rotor-related coordinate system. Current regulators control torque-producing and field-related components, then modulation generates complementary PWM. The position sensor provides the rotor-angle reference. Integration reduces component count and pin-level interconnects, while external MOSFETs allow package and loss selection. This is an explanation of the intended control architecture, not a claim that firmware already implements it. Sources: DESIGN_CONSTRAINTS.md, Fixed architecture, and FIRMWARE_BRINGUP_CONTRACT.md.

PRIMARY PROJECT SOURCES
ShiroFOC/ShiroFOC_KiCad/outputs/ShiroFOC_Rev_A_Schematic.pdf (A1-Drawing, 16 September 2026)
ShiroFOC/ShiroFOC_KiCad/outputs/ShiroFOC_Rev_A_BOM.csv
ShiroFOC/DESIGN_REVIEW_REV_A.md
ShiroFOC/FIRMWARE_BRINGUP_CONTRACT.md
Values are released schematic/BOM values unless marked as examples. Engineering reasoning beyond recorded intent is interpretation. No hardware qualification is implied.
IMAGE SOURCE: PDF page 1, crop overview.

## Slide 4

Power domains and operating modes

Supply state | Logic | Power stage
Battery only | 5V_BAT selected | Available after setup
USB only | 5V_USB selected | VM / VCC absent
Both valid | USB preferred | Available after setup
VM returns | MCU may stay alive | Reinitialize before arming

Control power survives USB service

5V_BAT and 5V_USB feed TPS2121. 5V_SYS feeds the external 3.3 V LDO.

Gate power follows VM

The internal STSPIN buck generates VCC independently of the 3.3 V control rail.

VM return requires reinitialization

USB can keep the MCU alive while the gate driver loses power. Restore VCC settings and protections before torque.

USB alone powers logic and sensors. It does not energize VM, VCC or either power switch stage.

KiCad schematic, page 3

04

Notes: The external logic rail supplies the embedded MCU, sensor interfaces, CAN and service bridge. The gate-driver rail depends on VM, so USB-only operation cannot drive the inverter or brake. Both input supplies may be attached because the mux provides reverse-current blocking. On VM loss, firmware invalidates motor state and clears torque commands. On return it repeats the driver setup rather than continuing from a stale command. Source: DESIGN_CONSTRAINTS.md, Auxiliary power architecture, and FIRMWARE_BRINGUP_CONTRACT.md, Runtime rules.

PRIMARY PROJECT SOURCES
ShiroFOC/ShiroFOC_KiCad/outputs/ShiroFOC_Rev_A_Schematic.pdf (A1-Drawing, 16 September 2026)
ShiroFOC/ShiroFOC_KiCad/outputs/ShiroFOC_Rev_A_BOM.csv
ShiroFOC/DESIGN_REVIEW_REV_A.md
ShiroFOC/FIRMWARE_BRINGUP_CONTRACT.md
Values are released schematic/BOM values unless marked as examples. Engineering reasoning beyond recorded intent is interpretation. No hardware qualification is implied.
IMAGE SOURCE: PDF page 3, crop mux.

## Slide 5

Battery entry and DC-link capacitance

2040 µF bulk capacitance

C101–C103 are 680 µF / 63 V each. The bank buffers short bus-energy changes.

Several capacitor scales

4.7 µF, 100 nF and 10 nF bypass paths support progressively faster current changes.

Ripple rating can be limiting

5.07 Arms is the summed 100 kHz nameplate rating. Actual sharing, frequency and temperature change the usable margin.

E = ½CV² = 1.80 J at 42 V

KiCad schematic, page 2

05

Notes: The parallel electrolytics provide 2.04 mF nominal capacitance. At 42 V the stored energy is 0.5 × 0.00204 × 42² = 1.799 J. This is much smaller than the example mechanical braking energy later in the deck, so the capacitor bank cannot replace a brake resistor. Bulk ESR contributes damping and heating. Ceramic capacitance falls with DC bias and its effectiveness depends on loop inductance. The nameplate ripple sum is not the actual permissible motor phase current. Measure capacitor current and case temperature during the load ramp. Sources: schematic page 2, BOM C101–C106, electrical_calculations.json bus section, and DESIGN_REVIEW_REV_A.md.

PRIMARY PROJECT SOURCES
ShiroFOC/ShiroFOC_KiCad/outputs/ShiroFOC_Rev_A_Schematic.pdf (A1-Drawing, 16 September 2026)
ShiroFOC/ShiroFOC_KiCad/outputs/ShiroFOC_Rev_A_BOM.csv
ShiroFOC/DESIGN_REVIEW_REV_A.md
ShiroFOC/FIRMWARE_BRINGUP_CONTRACT.md
Values are released schematic/BOM values unless marked as examples. Engineering reasoning beyond recorded intent is interpretation. No hardware qualification is implied.
IMAGE SOURCE: PDF page 2, crop dc.

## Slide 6

Inrush, discharge and input damping

Bidirectional battery path

Regenerated current can return to a suitable battery. Rev A omits reverse-polarity protection and active precharge.

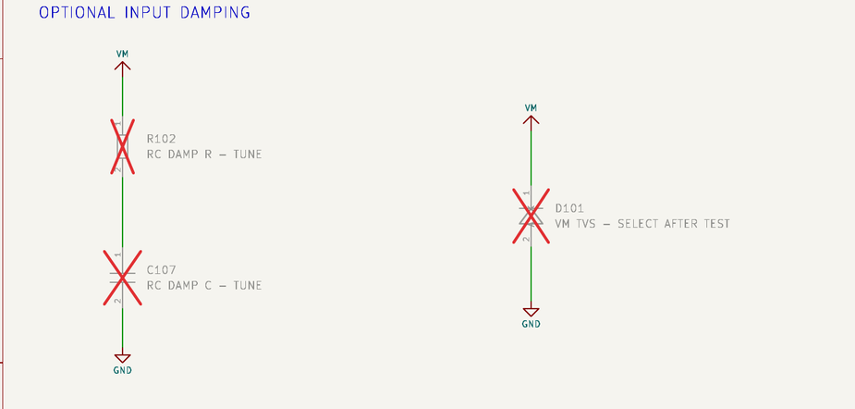
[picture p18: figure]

470 kΩ is a slow bleeder

R101 dissipates only 3.75 mW at 42 V. Bulk-only discharge has an approximately 16-minute time constant.

Damping remains unpopulated

D101 and R102/C107 need cable and hot-plug measurements before selecting values.

τ = 470 kΩ × 2040 µF = 959 s; external precharge/current limiting is required for first tests.

KiCad schematic, page 2

06

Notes: The bulk-only RC estimate excludes the converters and other attached loads, which can shorten measured discharge. One time constant leaves roughly 37 percent of the starting voltage, so the board is not discharged after 16 minutes merely because that is the time constant. Hot-plug cable inductance and low-ESR capacitance can produce a bus overshoot. An arbitrary input inductor can worsen this resonance. D101 is a DNP TVS placeholder. R102/C107 form a DNP series RC damping branch. TVS pulse clamping, inrush limiting and sustained regenerative dissipation are different functions. Source: schematic page 2 and DESIGN_CONSTRAINTS.md, Power entry, long cables, and inrush.

PRIMARY PROJECT SOURCES
ShiroFOC/ShiroFOC_KiCad/outputs/ShiroFOC_Rev_A_Schematic.pdf (A1-Drawing, 16 September 2026)
ShiroFOC/ShiroFOC_KiCad/outputs/ShiroFOC_Rev_A_BOM.csv
ShiroFOC/DESIGN_REVIEW_REV_A.md
ShiroFOC/FIRMWARE_BRINGUP_CONTRACT.md
Values are released schematic/BOM values unless marked as examples. Engineering reasoning beyond recorded intent is interpretation. No hardware qualification is implied.
IMAGE SOURCE: PDF page 2, crop damping.

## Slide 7

Bus divider and powered-off ADC isolation

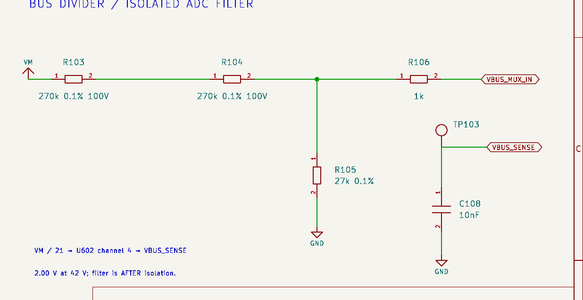
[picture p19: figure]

A 21:1 voltage scale

R103 + R104 = 540 kΩ. R105 = 27 kΩ. Splitting the upper leg distributes voltage stress.

267 µs nominal filtering

R106 = 1 kΩ and C108 = 10 nF. Divider impedance contributes most of the time constant.

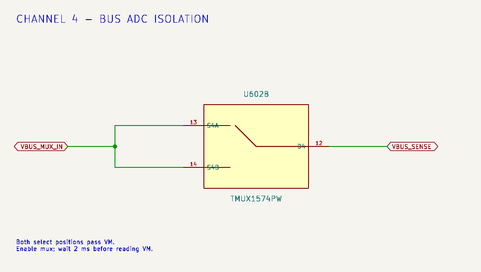
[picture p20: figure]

U602 isolates the live divider

The capacitor sits after isolation. Enable the mux and wait at least 2 ms before trusting VM.

VADC = VM / 21 = 2.00 V at 42 V; VM sensing is invalid whenever the feedback mux is disabled.

KiCad schematic, page 2 + 10

07

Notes: RTH = 540 kΩ parallel 27 kΩ = 25.714 kΩ. Including the series 1 kΩ gives τ = 267.14 µs, neglecting the much smaller mux on-resistance. Two milliseconds corresponds to approximately 7.49 time constants, giving about 0.056 percent residual ideal settling error. At 60 V the divider would produce 2.857 V, a headroom calculation rather than permission to operate at 60 V. Both channel-4 mux inputs connect to the divided bus, so position-source selection does not alter the divider scale. Disabling the common mux enable still removes VM sensing. Sources: schematic pages 2 and 10, electrical_calculations.json bus section, firmware contract.

PRIMARY PROJECT SOURCES
ShiroFOC/ShiroFOC_KiCad/outputs/ShiroFOC_Rev_A_Schematic.pdf (A1-Drawing, 16 September 2026)
ShiroFOC/ShiroFOC_KiCad/outputs/ShiroFOC_Rev_A_BOM.csv
ShiroFOC/DESIGN_REVIEW_REV_A.md
ShiroFOC/FIRMWARE_BRINGUP_CONTRACT.md
Values are released schematic/BOM values unless marked as examples. Engineering reasoning beyond recorded intent is interpretation. No hardware qualification is implied.
IMAGE SOURCE: PDF page 2, crop divider.

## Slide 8

Battery-to-5 V buck converter

LMR36510F at 400 kHz

A switching converter avoids dissipating the large VM-to-5 V drop as heat. Forced PWM keeps predictable switching at light load.

22 µH inductor

Nominal ripple is 0.41–0.50 A peak-to-peak over 18–42 V for approximately 5 V output.

44 µF nominal output bank

Two 22 µF ceramics support load transients. Effective capacitance and regulator stability still require review.

VOUT = 1.00 × (1 + 100 kΩ / 24.9 kΩ) = 5.016 V

KiCad schematic, page 3

08

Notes: U201 is LMR36510FADDAR, the forced-PWM 400 kHz variant. R201/R202 set the adjustable output. For an ideal buck in continuous conduction, ΔIL = VOUT(1 − VOUT/VIN)/(L fSW). At 18 and 42 V using 5.016 V, 22 µH and 400 kHz this gives approximately 0.411 and 0.502 A peak-to-peak. At a 1 A average load the nominal inductor peak is about 1.25 A, before tolerances or transients. The 2.75 A inductor rating is not a guarantee of regulator current capability. Low oscillator frequency and reduced inductance increase ripple. C203 = 100 nF supports the buck bootstrap, C204 = 1 µF bypasses the internal bias rail, C201/C202 bypass VM, and C205/C206 support output load transients. Sources: schematic page 3, local LMR36510 datasheet Device Comparison and switching-frequency specification; Wurth 74437349220 datasheet.

PRIMARY PROJECT SOURCES
ShiroFOC/ShiroFOC_KiCad/outputs/ShiroFOC_Rev_A_Schematic.pdf (A1-Drawing, 16 September 2026)
ShiroFOC/ShiroFOC_KiCad/outputs/ShiroFOC_Rev_A_BOM.csv
ShiroFOC/DESIGN_REVIEW_REV_A.md
ShiroFOC/FIRMWARE_BRINGUP_CONTRACT.md
Values are released schematic/BOM values unless marked as examples. Engineering reasoning beyond recorded intent is interpretation. No hardware qualification is implied.
IMAGE SOURCE: PDF page 3, crop buck.

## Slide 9

USB-priority power mux

Different priority divider ratios

15 kΩ / 5.10 kΩ on battery and 10 kΩ / 5.10 kΩ on USB set USB preference.

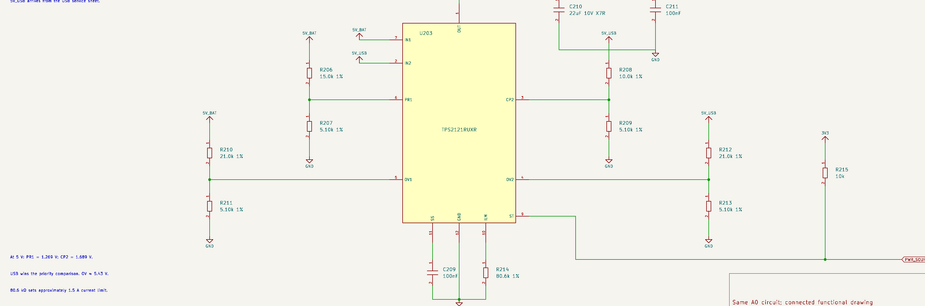
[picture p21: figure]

Defined input thresholds

21 kΩ / 5.10 kΩ dividers set approximately 5.43 V overvoltage thresholds.

Current limit and soft start

80.6 kΩ sets approximately 1.5 A. C209 = 100 nF controls startup slew.

At 5 V: PR1 = 1.269 V and CP2 = 1.689 V, so valid USB takes priority.

KiCad schematic, page 3

09

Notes: TPS2121 isolates the sources and selects a preferred input. PR1 = 5 × 5.10/(15.0+5.10) and CP2 = 5 × 5.10/(10.0+5.10). The recorded OV setting uses a nominal 1.06 V reference: 1.06 × (21+5.10)/5.10 ≈ 5.425 V. These are nominal values, and the full datasheet threshold and resistor tolerances must be included in qualification. C210 = 22 µF and C211 = 100 nF bypass the mux output. R215 = 10 kΩ pulls its status signal to 3V3. Soft-start timing depends on the device SS behavior and output loading. The 1.5 A setting does not authorize drawing that current from USB. Sources: schematic page 3, DESIGN_REVIEW_REV_A.md and TPS2121 datasheet, priority, OV, ILM and SS sections.

PRIMARY PROJECT SOURCES
ShiroFOC/ShiroFOC_KiCad/outputs/ShiroFOC_Rev_A_Schematic.pdf (A1-Drawing, 16 September 2026)
ShiroFOC/ShiroFOC_KiCad/outputs/ShiroFOC_Rev_A_BOM.csv
ShiroFOC/DESIGN_REVIEW_REV_A.md
ShiroFOC/FIRMWARE_BRINGUP_CONTRACT.md
Values are released schematic/BOM values unless marked as examples. Engineering reasoning beyond recorded intent is interpretation. No hardware qualification is implied.
IMAGE SOURCE: PDF page 3, crop mux.

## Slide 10

3.3 V LDO and control-power budget

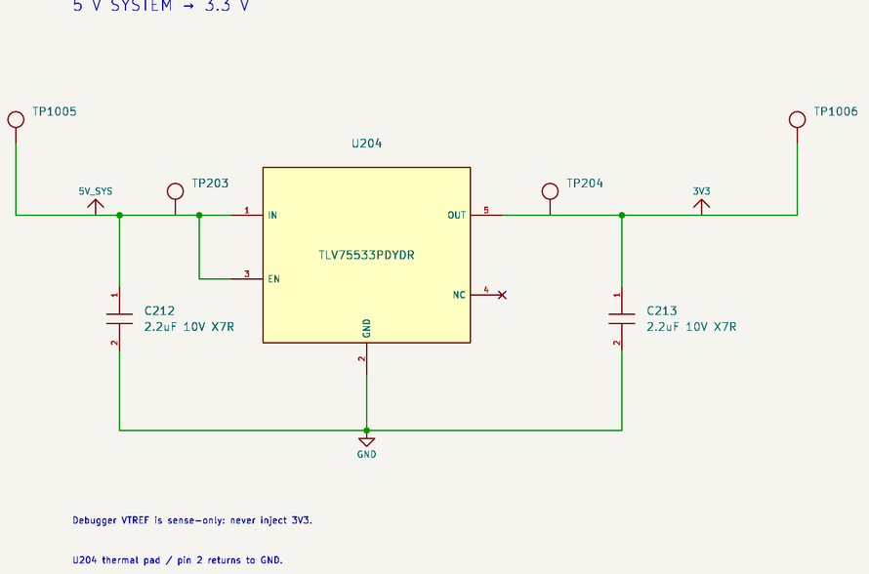
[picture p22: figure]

TLV75533P supplies the logic rail

The external 500 mA regulator supports both battery and USB operation while bypassing the STSPIN internal 3.3 V regulator.

250 mA planning allowance

The recorded CAN-fault allowance raises this to 320 mA. External feedback is limited to 25 mA.

Thermal loss matters

At 5.25 V input, the LDO dissipates 0.488 W normally or 0.624 W at the fault allowance.

PLDO = (VIN − 3.3 V) × ILOAD

KiCad schematic, page 3

10

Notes: The current budget allocates 100 mA for MCU/driver logic, 25 mA encoder, 10 mA IMU, 61 mA dominant CAN, 20 mA CP2102N, 25 mA external feedback, and 9 mA miscellaneous, totaling 250 mA. The normal budget contains planning allowances rather than a measured operating current. C212/C213 are 2.2 µF each and must retain sufficient effective capacitance for the LDO requirements. Linear regulation simplifies the rail and avoids an additional switching node, at the cost of heat. The DYD thermal pad connects to ground. Junction temperature depends on real copper and enclosure temperature. Sources: electrical_calculations.json logic_budget_mA, schematic page 3, TLV755P datasheet.

PRIMARY PROJECT SOURCES
ShiroFOC/ShiroFOC_KiCad/outputs/ShiroFOC_Rev_A_Schematic.pdf (A1-Drawing, 16 September 2026)
ShiroFOC/ShiroFOC_KiCad/outputs/ShiroFOC_Rev_A_BOM.csv
ShiroFOC/DESIGN_REVIEW_REV_A.md
ShiroFOC/FIRMWARE_BRINGUP_CONTRACT.md
Values are released schematic/BOM values unless marked as examples. Engineering reasoning beyond recorded intent is interpretation. No hardware qualification is implied.
IMAGE SOURCE: PDF page 3, crop ldo.

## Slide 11

MCU, clock, reset and SWD

24 MHz crystal, 7 pF load

Two 10 pF C0G capacitors contribute 5 pF series load, leaving approximately 2 pF for stray capacitance.

Controlled reset and boot states

Reset pull-up/filter and BOOT0 defaults support predictable startup. PB8 shares the feedback index/Hall input.

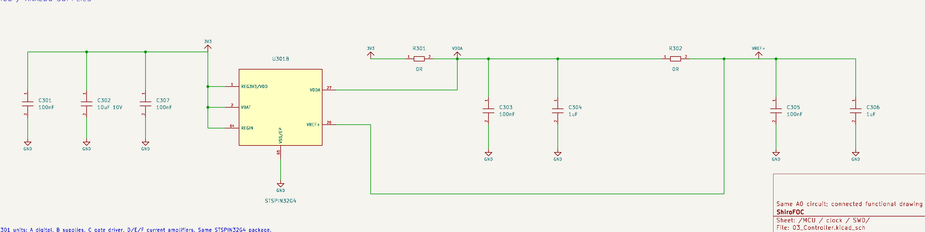
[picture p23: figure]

Debug and analog supplies

SWD remains available. Local bypassing serves VDD, VDDA and VREF+. VTREF is a sense connection.

CL ≈ C1C2 / (C1 + C2) + Cstray

KiCad schematic, page 4 + 4

11

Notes: The 10 pF capacitors are starting values for a 7 pF crystal load, because two equal 10 pF capacitors contribute 5 pF in series. Pin, trace and package capacitance supplies the remaining assumed 2 pF. The oscillator must be verified for startup and frequency. R303 = 100 kΩ with C310 = 100 nF gives a nominal 10 ms external reset RC, although actual reset behavior includes device thresholds and internal circuitry. R304 = 1 kΩ limits LED current to roughly (3.3 − VF − VOL)/1000. R301/R302 are 0 Ω analog supply links with local 100 nF and 1 µF bypassing; they are not designed ferrite filters. PB3 is SPI SCK, so SWO is absent. The short R1001/button branch permits manual BOOT0 control, and the feedback mux isolates PB8 through reset. Sources: schematic page 4, BOM and firmware contract.

PRIMARY PROJECT SOURCES
ShiroFOC/ShiroFOC_KiCad/outputs/ShiroFOC_Rev_A_Schematic.pdf (A1-Drawing, 16 September 2026)
ShiroFOC/ShiroFOC_KiCad/outputs/ShiroFOC_Rev_A_BOM.csv
ShiroFOC/DESIGN_REVIEW_REV_A.md
ShiroFOC/FIRMWARE_BRINGUP_CONTRACT.md
Values are released schematic/BOM values unless marked as examples. Engineering reasoning beyond recorded intent is interpretation. No hardware qualification is implied.
IMAGE SOURCE: PDF page 4, crop clock.
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

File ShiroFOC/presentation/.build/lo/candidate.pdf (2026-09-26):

# ShiroFOC hardware design

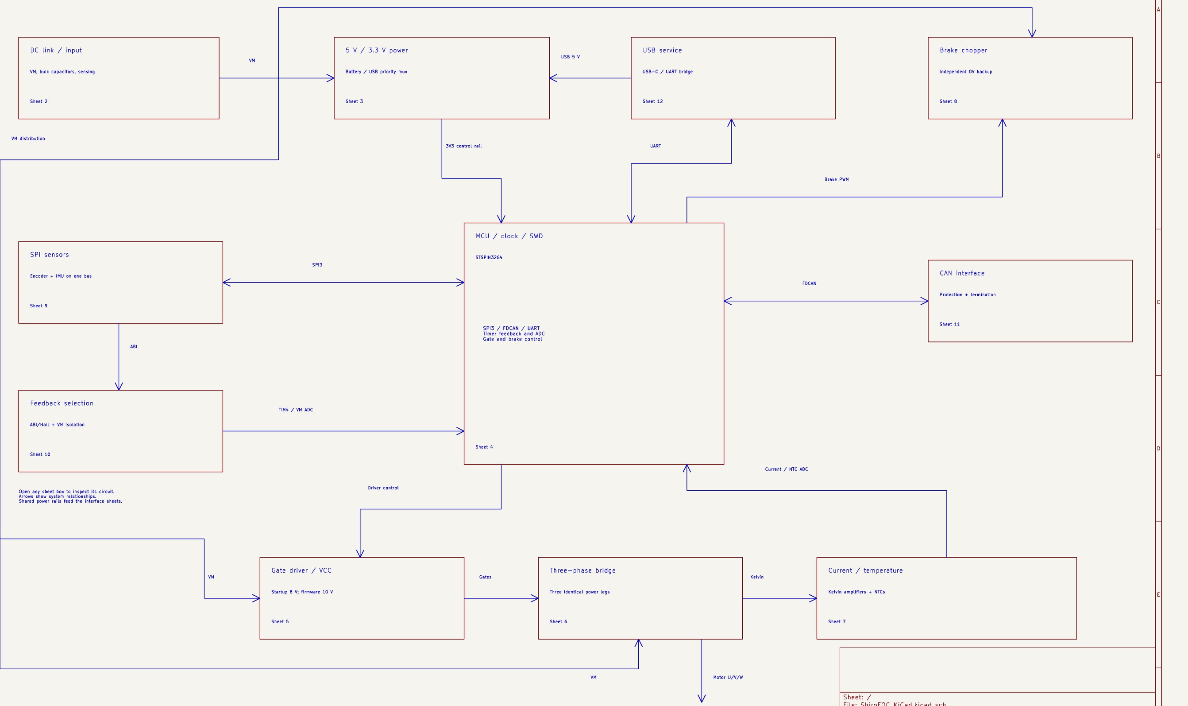
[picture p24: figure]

KiCad schematic, page 1 | 01

Schematic topology and component decisions

## A single-axis FOC servo module

Topology, component choices and the measurements that establish the operating envelope.

A1 drawing / A0 electrical design

16 September 2026
36 review slides + 5 technical appendices

Prototype targets. Hardware qualification remains open.

# Electrical requirements and operating envelope

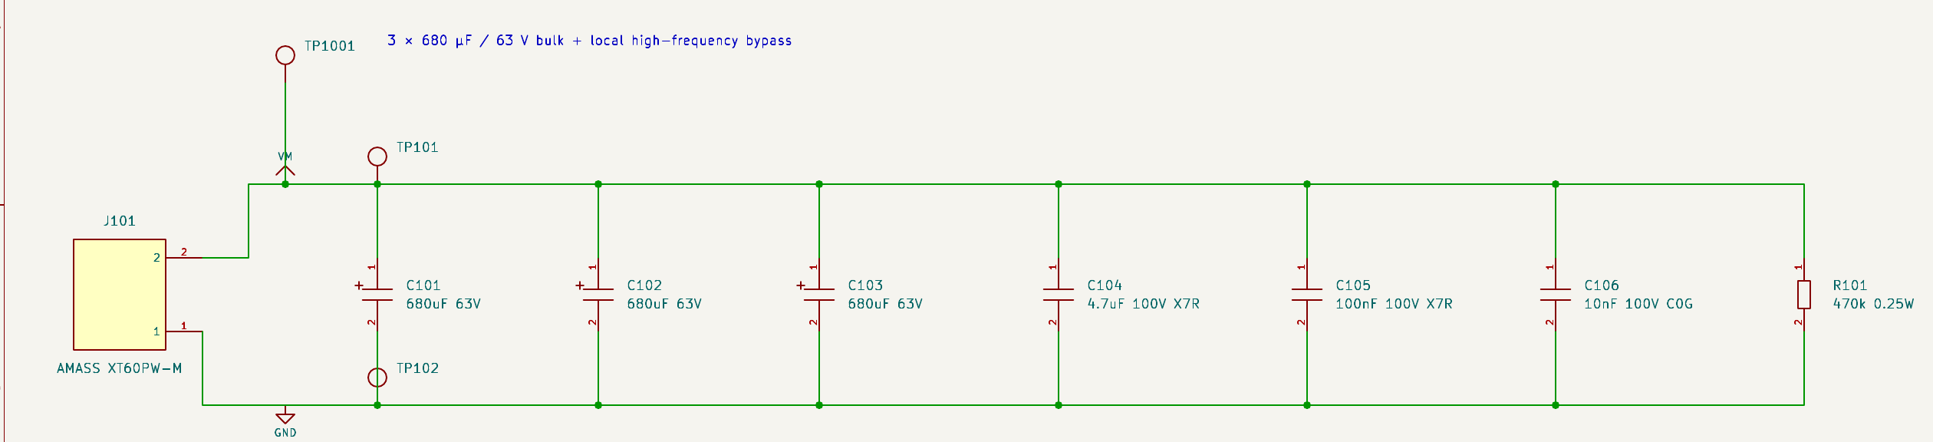
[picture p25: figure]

KiCad schematic, page 2 | 02

### 18–42 V bus

6S–10S packs. The preferred design point is 8S: 29.6 V nominal, 33.6 V fully charged.

### 25 / 40 Arms targets

Passive cooling / a defined thermal solution. Phase current differs from battery current.

### 80 A peak is a future target

At most 2 s, subject to qualification. Initial +60 A protection prevents treating this as an enabled rating.

60 V MOSFET absolute maximum requires margin for regeneration and switching overshoot.

# System architecture and FOC signal flow

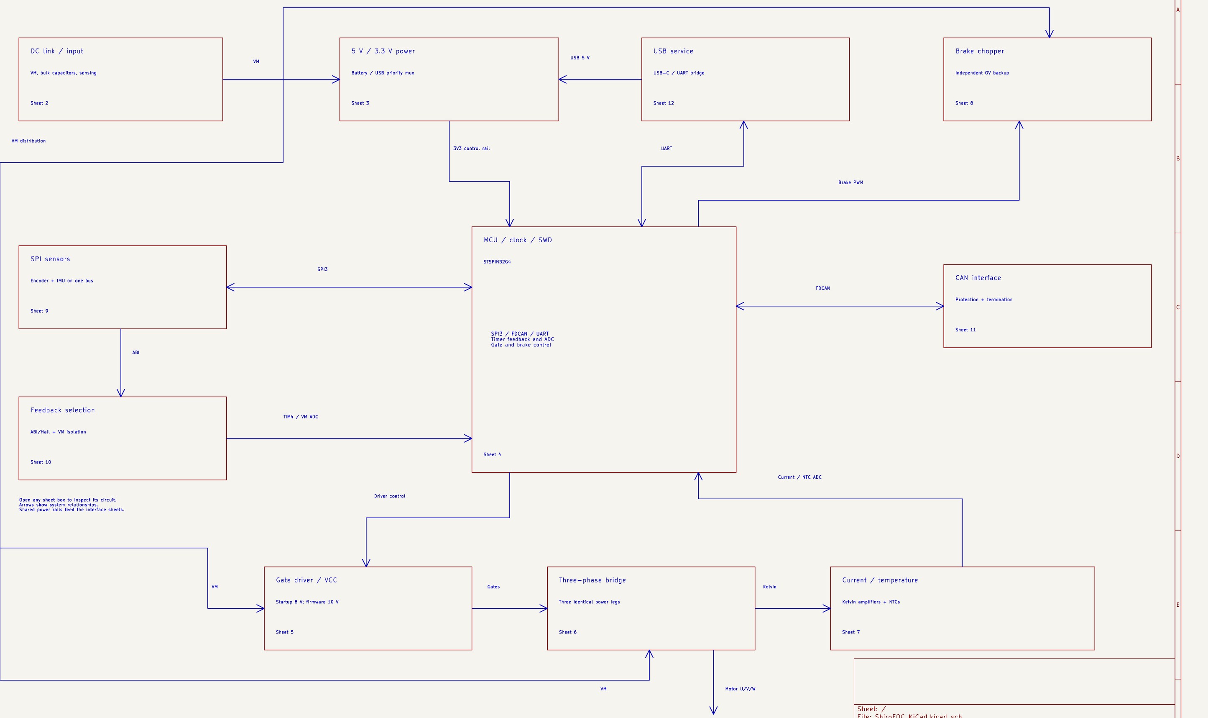
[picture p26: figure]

KiCad schematic, page 1 | 03

### Local current control

Shunts measure phase current. The MCU uses rotor position and current feedback to calculate PWM.

### Outer motion loops

Velocity and position loops set the requested torque-producing current. CAN coordinates modules.

### Integrated control, external power

U301 combines the MCU, driver and analog resources. External MOSFETs set power-stage capability.

Position feedback + phase current + synchronized PWM form the local control loop.

# Power domains and operating modes

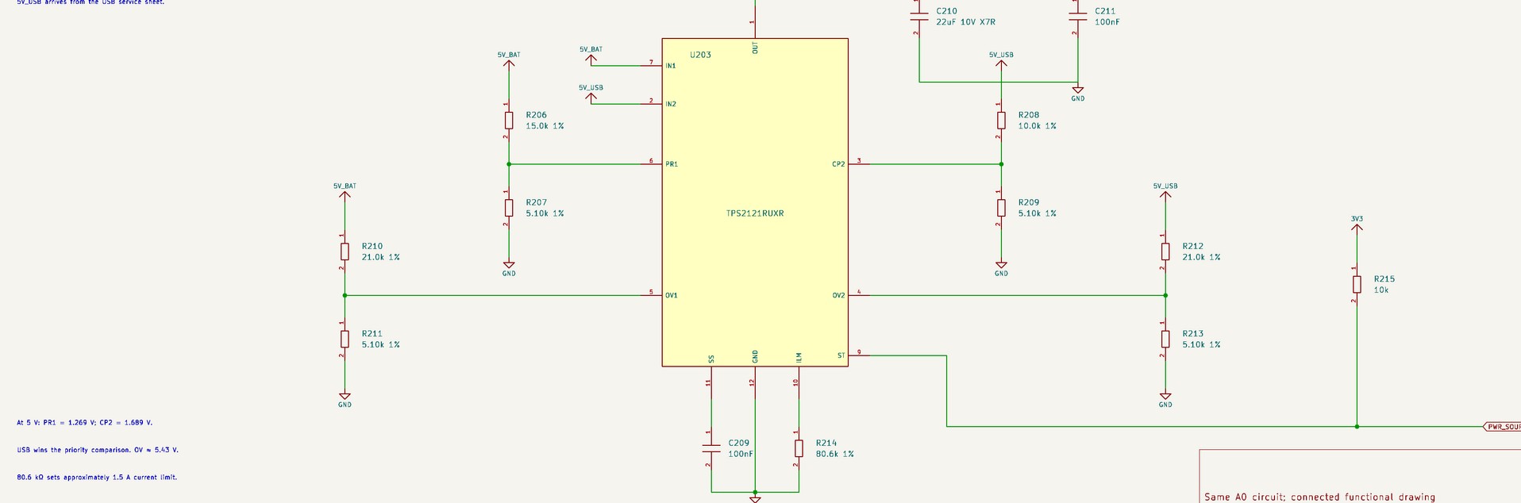
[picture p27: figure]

KiCad schematic, page 3 | 04
Supply state | Logic | Power stage
Battery only | 5V_BAT selected | Available after setup
USB only | 5V_USB selected | VM / VCC absent
Both valid | USB preferred | Available after setup
VM returns | MCU may stay alive | Reinitialize before arming

### Control power survives USB service

5V_BAT and 5V_USB feed TPS2121. 5V_SYS feeds the external 3.3 V LDO.
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

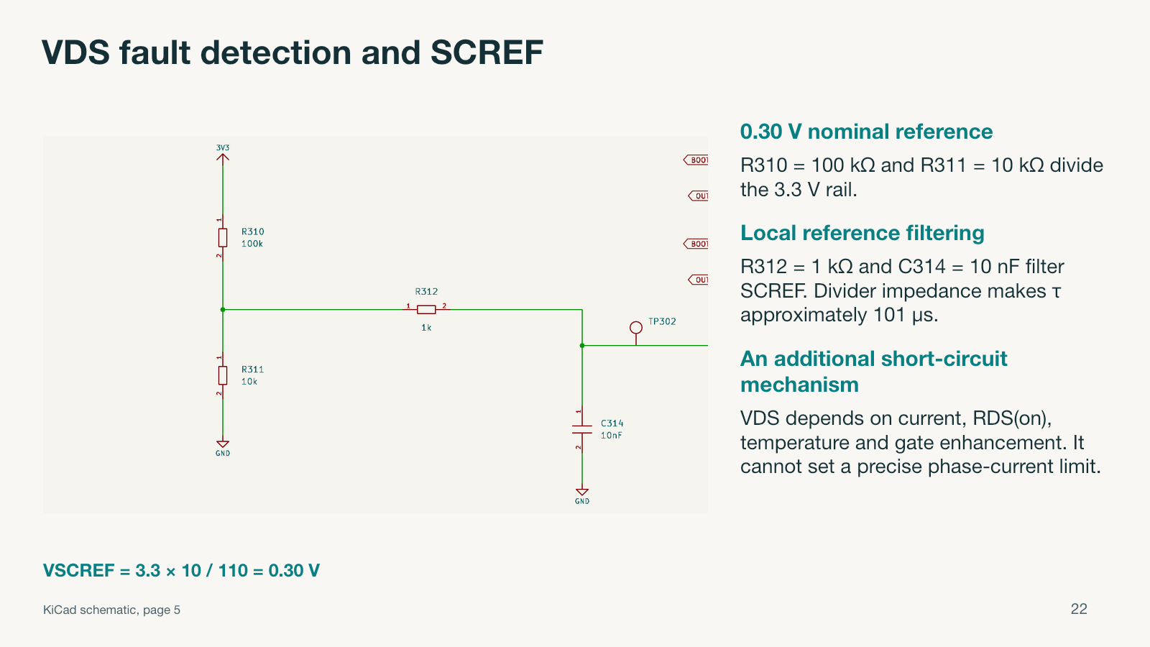
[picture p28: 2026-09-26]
ShiroFOC/presentation/.build/render/slide-22.png

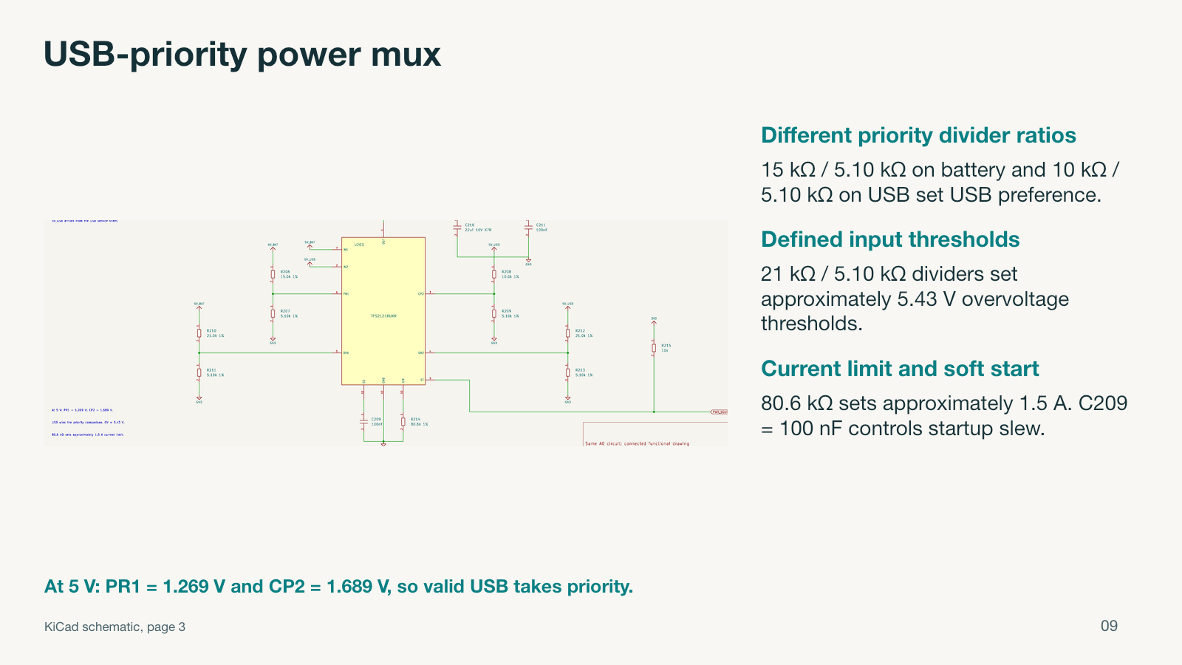
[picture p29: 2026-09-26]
ShiroFOC/presentation/.build/render/slide-09.png

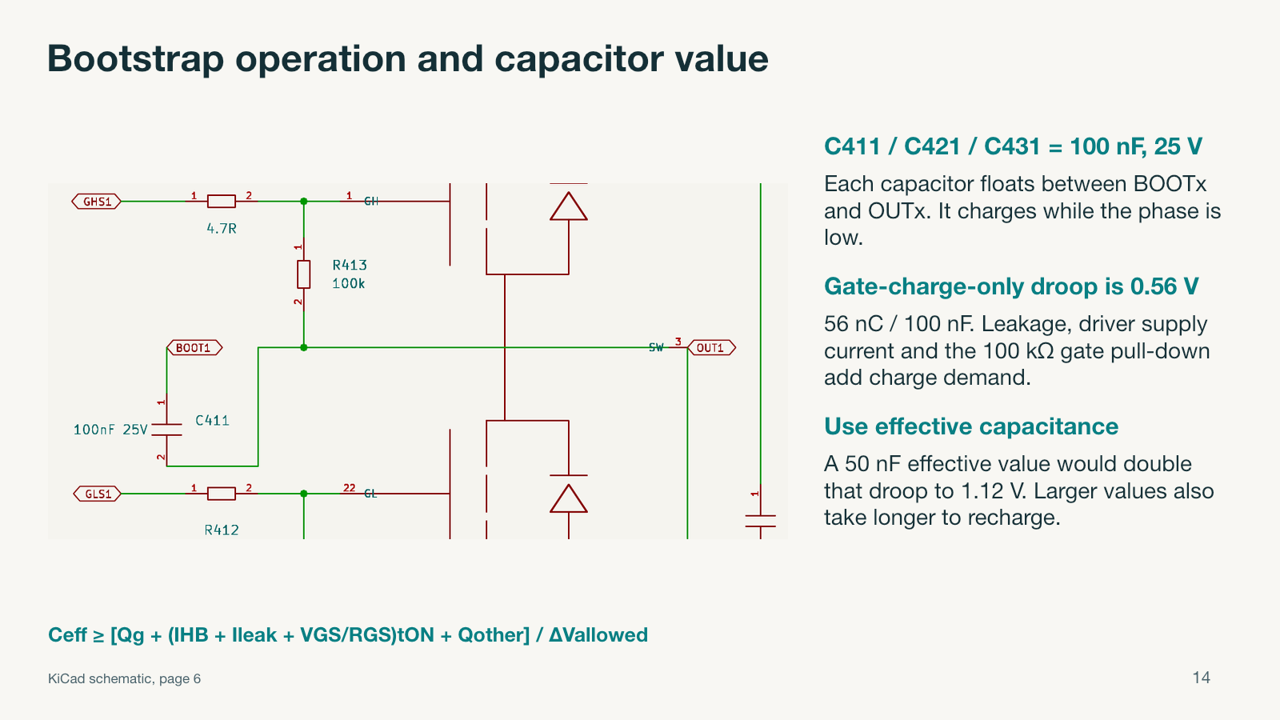
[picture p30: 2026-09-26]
ShiroFOC/presentation/.build/render/slide-14.png

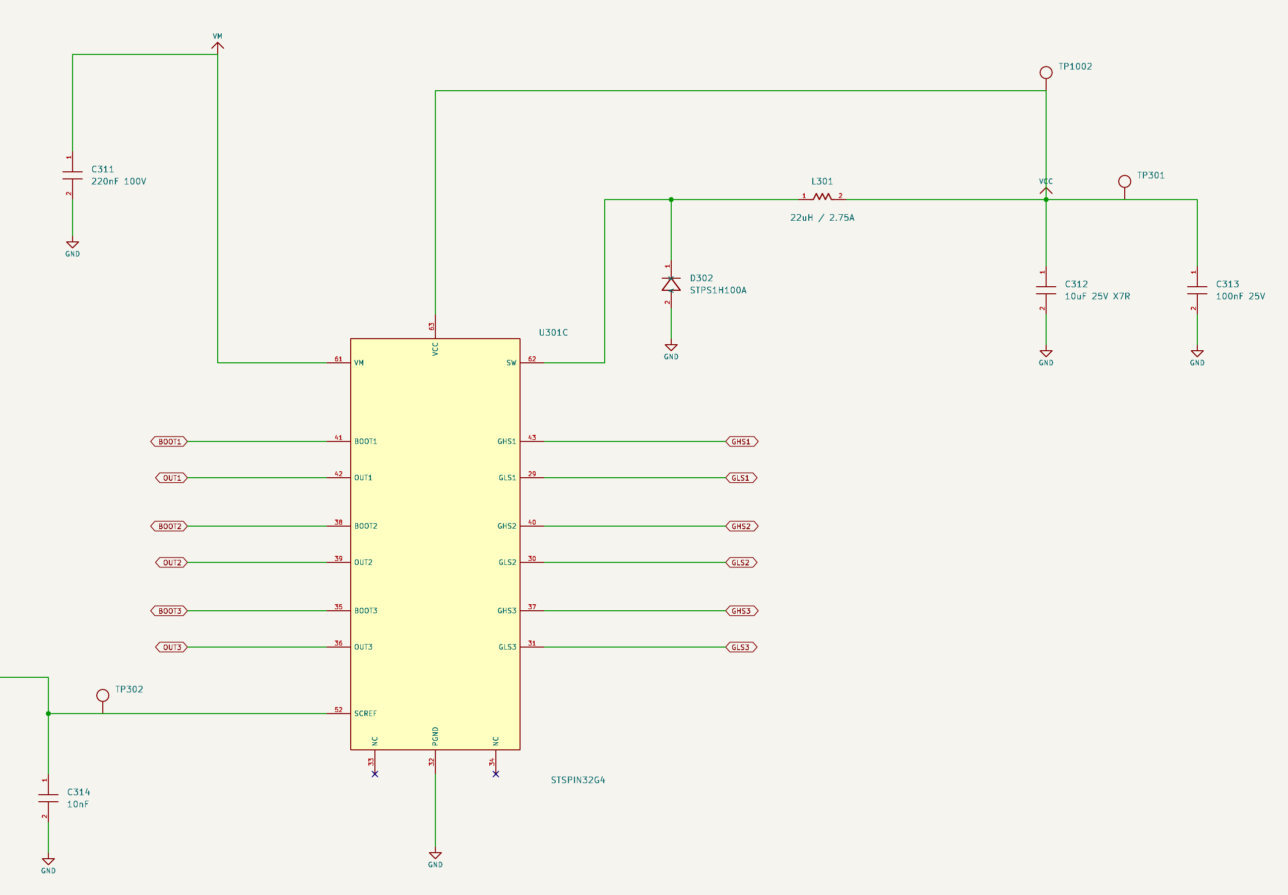
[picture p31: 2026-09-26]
ShiroFOC/presentation/.build/assets/gate.png

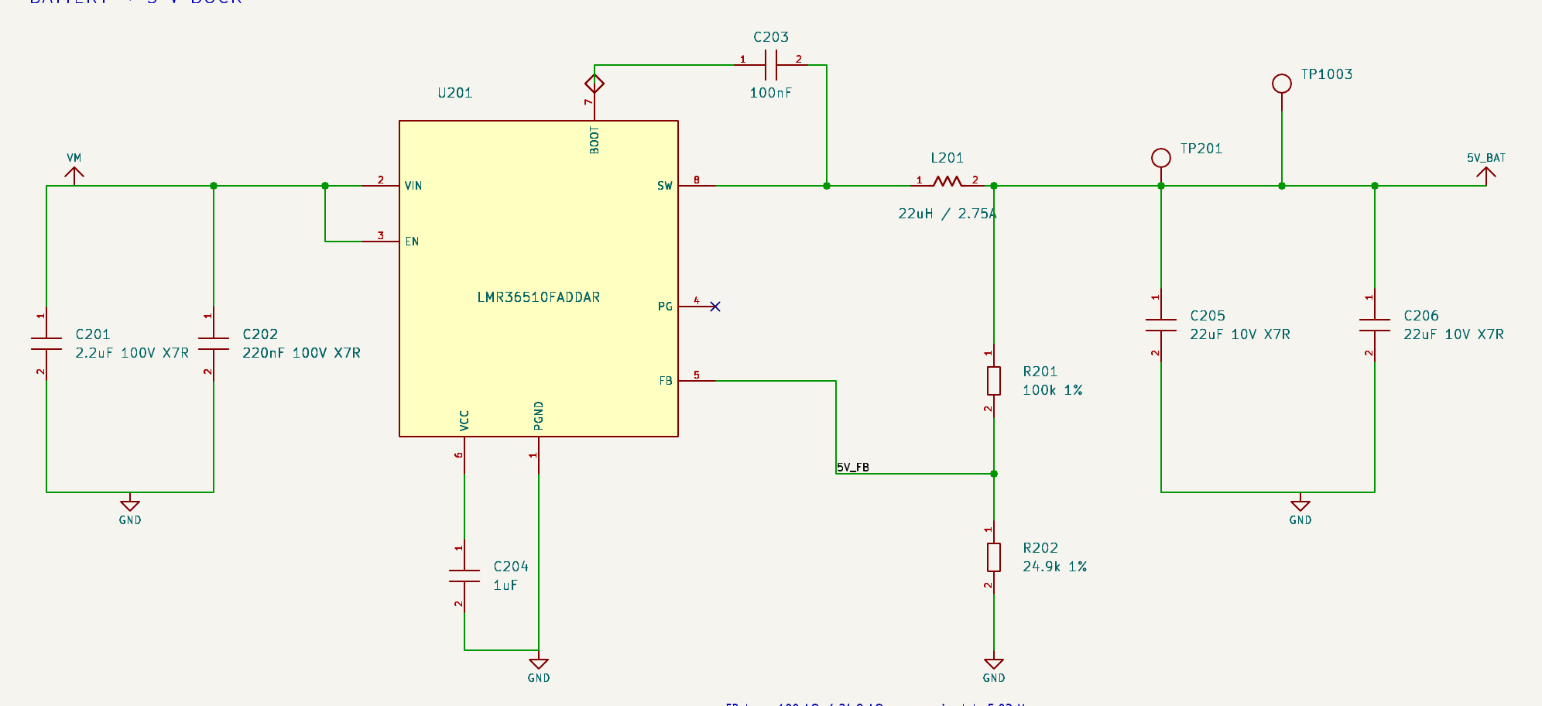
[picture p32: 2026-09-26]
ShiroFOC/presentation/.build/assets/buck.png

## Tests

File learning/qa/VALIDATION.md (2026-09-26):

# Validation and limitations

## Completed

- Read the native schematic with the KiCad analyzer; manually checked key values and connections against the P1 netlist, particularly sense nodes and DNP feedback capacitors.
- Checked the half-bridge periodic mean current against its specified operating point.
- Checked three-phase current summation and analytical mean input current.
- Checked capacitor charge balance and Kirchhoff current balance in the periodic network model.
- Recomputed representative three-phase cases at twice the time resolution; see [numerical_checks.json](numerical_checks.json) for actual differences.
- Compared the browser's exact 2×2 transient solution against independent SciPy state-space results for underdamped, overdamped and critically damped cases. See [javascript_checks.json](javascript_checks.json).
- Swept extreme transient control values for finite outputs and checked passive impedances remain finite and positive.
- Checked HTML IDs, referenced controls, links and local artifact paths; see [artifact_checks.json](artifact_checks.json).
- Exercised all seven navigation handlers and 85 control updates using DOM/canvas stubs, including minimum/maximum values. All plotted coordinates and result text remained finite. This checks script wiring, not actual browser layout; see [lab_wiring_checks.json](lab_wiring_checks.json).
- Inspected the standalone exported figures visually. These use the same physical models described in the model guide.

## Explicit gaps

**Interactive browser rendering was not visually verified.** Automatic navigation to the local HTML file was rejected by the browser's local-file security policy. No alternate browser route was used to bypass that block. The code, references and numerical functions were checked directly. Open `index.html` locally to use the delivered lab.

**No successful SPICE verification is claimed.** A skill-driven LTspice batch attempt detected the installed application, but its calls failed without useful simulator output; all twenty attempted automatic cases were skipped. The raw attempt is retained in [spice_attempt.json](../data/spice_attempt.json). Some automatic divider detections also do not represent the complete relevant circuit. None was treated as evidence against the board. The curated numerical models and manually checked topology are the teaching basis.

**This is not a full design review.** No fabricated board measurements, switching-device nonlinear model, routed parasitic extraction, EMC test, thermal qualification, parts-availability validation or fabricator validation was performed. The physical assumptions dominate uncertainty even where numerical agreement is excellent.

## Reproduce

From the repository root, after installing the model requirements:

```sh
python learning/models/build_models.py
python learning/models/build_package.py
python learning/models/validate_reference.py
node learning/models/check_models.cjs
node learning/models/check_lab_wiring.cjs
node --check learning/lab.js
```

`ShiroFOC_learning.ipynb` contains runnable code cells, with no fabricated execution outputs. The underlying model functions were executed by the scripts above. Optional notebook display imports require a Jupyter environment; the offline HTML lab does not.

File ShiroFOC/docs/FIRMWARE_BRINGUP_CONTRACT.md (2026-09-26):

> **Historical A0 document — superseded for Manual_Rebuild.** Use the [current firmware requirements](../requirements/FIRMWARE_REQUIREMENTS.md). In particular, do not implement the shared SPI mode switching, internal 8-to-10 V regulator setup, old current targets or unverified comparator example below on the current board.

# ShiroFOC A0 firmware and bring-up contract

This is a hardware interface contract, not implemented firmware. Follow [MCU pin allocation](MCU_PINOUT_AND_INTERFACE_PLAN.md) and the native schematic. Peripheral capability was checked from the STSPIN32G4 pin table; STM32CubeMX has not been run. Generate and review the actual clock/peripheral configuration during firmware work.

## Initialization before any torque

1. Keep TIM1 MOE cleared and all inverter PWM outputs inactive. PB9 brake PWM starts low. CAN_STB/PB10 stays high. Hardware holds PC14/FEEDBACK_ENABLE_N high, PD2/FEEDBACK_SELECT low, and PB8/BOOT0 low.
2. Configure SWD-only debug so PB3/PB4/PA15 can serve SPI/CS. Start HSE/PLL with a checked 24 MHz clock configuration; retain recovery on SWD.
3. Deassert both sensor chip selects before enabling SPI. Encoder uses SPI mode 1; BMI323 mode 0 or 3. Serialize transactions and change mode only with both CS high.
4. Configure feedback A/B/I or Hall inputs and TIM4; set PD2 source selection, preload PC14 high, then drive it low to enable the TMUX. Wait **at least 2 ms** before accepting VBUS_SENSE. Channel 4 also switches the VM divider, so VM is invalid whenever the feedback mux is disabled.
5. Start/calibrate ADCs and OPAMP1/2/3 in the external feedback configuration. Measure all current offsets with PWM off. Configure comparator thresholds through the internal DAC paths and route **COMP1/2/4 into TIM1 break**. Keep automatic restart disabled; latch a fault until explicitly cleared under safe conditions.
6. Configure the internal STSPIN I2C3 link and gate-driver interlocking/minimum deadtime/VDS protection. Read faults/READY; select **10 V VCC** from its default 8 V after each VM power-up. Require valid VM, VCC/READY and fault-free status before enabling PWM.
7. Initialize FDCAN TX recessive before driving PB10 CAN_STB low. Check temperatures, feedback plausibility and bus limits. Require an explicit arm command; never arm from a stale pre-reset command.
8. Begin at 18 V on a current-limited source, motor unloaded, very low commanded phase current (1–2 A). Start 20 kHz center-aligned PWM and 500 ns programmed deadtime; verify waveforms before reducing deadtime or raising current.

## Analog/peripheral map

| Function | MCU pins | Configuration |
|---|---|---|
| U current | PA1 +, PA3 −, PA2 output | OPAMP1; ADC1 channel 3; COMP1 positive input PA1 |
| V current | PA7 +, PC5 −, PA6 output | OPAMP2; ADC2 channel 3; COMP2 positive input PA7 |
| W current | PB0 +, PB2 −, PB1 output | OPAMP3; ADC1 channel 12; COMP4 positive input PB0 |
| VM | PA0 | ADC1/2 channel 1, divided by 21; only valid with TMUX enabled |
| NTC U/V/W | PC3 / PC0 / PC1 | ADC1/2 channels 9 / 6 / 7 |
| Encoder/Hall | PB6 / PB7 / PB8 | TIM4 CH1/CH2/CH3; index or Hall mode; PB8 shares BOOT0 |
| Brake PWM | PB9 | TIM17_CH1; separate from TIM4 |
| CAN | PA11 RX / PA12 TX; PB10 STB | FDCAN1; STB high is standby |
| UART | PA9 TX / PA10 RX | USART1 to CP2102N through 100 Ω |
| SPI | PB3 SCK / PB4 MISO / PB5 MOSI | SPI3; PA15 encoder CS, PC4 IMU CS |
| IMU interrupts | PA4 / PA5 | EXTI4 / EXTI5 |
| Internal inverter PWM | PE8–PE13 | STSPIN internal TIM1 complementary PWM connections; not exposed package pins |
| Internal driver status | PE14 READY / PE15 NFAULT | Preserve ST's required TIM1 break-capable connections |

ADC1 is shared by U and W: do not assume simultaneous sampling of all three currents. Use valid low-side conduction windows, synchronized injected conversions, and reconstruct the third phase when appropriate. Account for switching blanking, op-amp settling and minimum sampling time. OPAMP3 also has internal ADC routing options; any use must be confirmed in the exact device configuration. Set a maximum modulation limit until sampling and bootstrap refresh are demonstrated.

The comparator positive inputs are the biased **op-amp inputs**, not the amplified ADC outputs. With SENSE_N near ground, `VCOMP = (56 × 0.0005 × I + 3.3)/58`. Internal DAC choice is DAC3 channel 1 for COMP1 and DAC3 channel 2 for COMP2/COMP4, according to ST's G4 LL interface. Confirm the exact register configuration and internal DAC mode in the firmware project. A nominal +60 A setting is about 85.86 mV / code 107, but offset/DAC errors can shift this substantially. Calibrate and demonstrate shutdown at reduced test current before enabling a higher threshold. Apply software limits to both current polarities; this one-sided comparator setup does not give a precise negative-current trip.

## Runtime rules

- Invalidate VM readings before disabling the feedback mux. Disable inverter PWM first; change source only at zero torque, then re-enable, settle and validate feedback/VM.
- Monitor VM independently of command traffic. Starting 10S software brake threshold: 43 V; use hysteresis/duty limiting and the installed resistor's energy/temperature model. Hardware OV backup is approximately 45.9/44.2 V. It may command the brake even while the MCU is reset.
- Do not arm without a suitable energy sink. An open/absent external resistor is not detected by this circuit; installation configuration and commissioning must establish its presence. Do not rely on the battery or PSU to absorb energy without verification.
- On VM loss while USB remains, clear torque commands and driver state. On VM return, repeat driver/VCC/protection setup; do not resume motion automatically.
- On comparator break, VDS fault, encoder loss, illegal Hall state, overtemperature or implausible NTC/ADC reading, latch inverter off. NTC short reads near zero and open near VREF. Use the hottest valid reading and characterize thermal lag.
- Before enabling CAN, hold TX recessive and configure the controller; stay in standby through reset. Apply end termination only where physically appropriate.
- USB-only operation is service mode; VM/VCC absent means no power-stage commands. Configure the CP2102N power descriptors for the actual service-power arrangement. Suspend/current-compliance load control is not provided by this hardware.

## Hardware commissioning sequence

1. Visual/continuity inspection, then USB/control power only from an allowed source. Measure 3V3, regulator temperature, standby current and absence of VM/VCC backfeed; flash via SWD.
2. Apply VM with current limiting and external precharge. Test battery-only, USB-only and both sources in both orders, including brownout, erased MCU and reset with active feedback inputs.
3. Verify 5V_BAT, mux source priority, 3V3, VCC default/programmed voltage and restart behavior. Scope switching/overshoot using probes appropriate to the bus voltage.
4. Calibrate current, VM and NTC channels. Inject controlled low-energy shunt/COMP stimuli and prove TIM1 turns off without executing a software ISR. Verify NFAULT/READY breaks and latch behavior.
5. Fit the qualified external resistor; test hardware OV thresholds with a current-limited source and verify brake current, gate drive and lead-voltage clamp. Test with MCU held reset. Do not test an intentional resistor short at high energy.
6. Spin unloaded at low current, inspect gate deadtime, bootstrap refresh, phase-node overshoot, current waveform and feedback timing. Keep sustained VM below 48 V during characterization and target measured MOSFET VDS peaks below 55 V; never approach the 60 V absolute maximum.
7. Increase voltage/current only after protection works. Measure capacitor RMS ripple, MOSFET/shunt/connector/LDO temperatures, external resistor energy and cooling. The 25/40 Arms and 80 A peak goals remain gated by these results.

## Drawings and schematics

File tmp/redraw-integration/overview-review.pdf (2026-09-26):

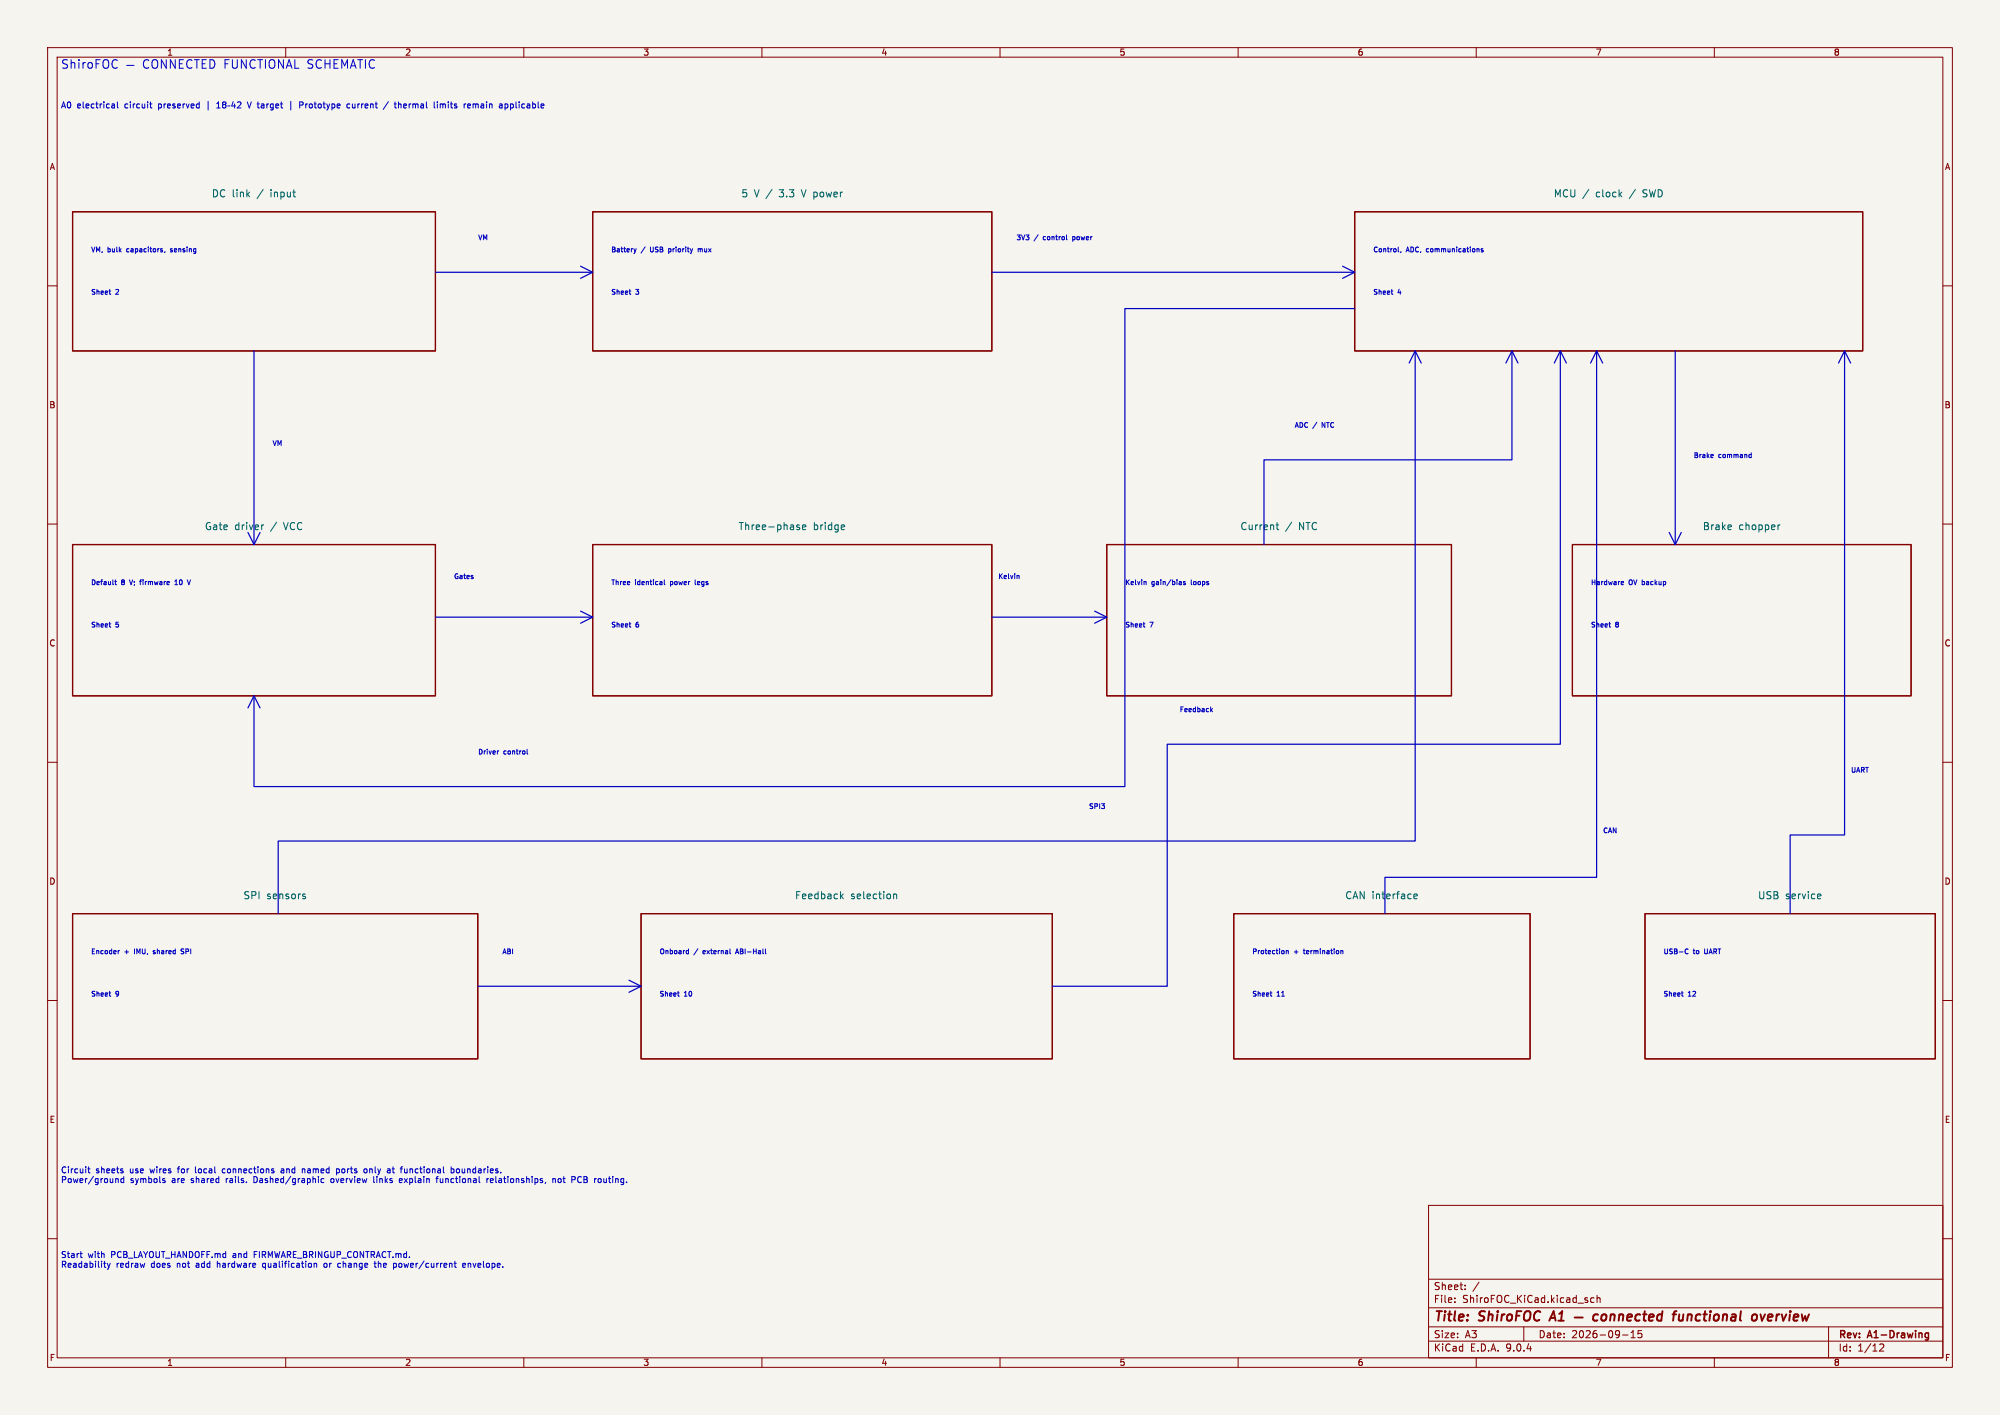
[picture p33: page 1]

Encoder + IMU, shared SPI

File: ShiroFOC_KiCad.kicad_sch Sheet: /
Id: 1/12 Title: ShiroFOC A1 þÿ connected functional overview

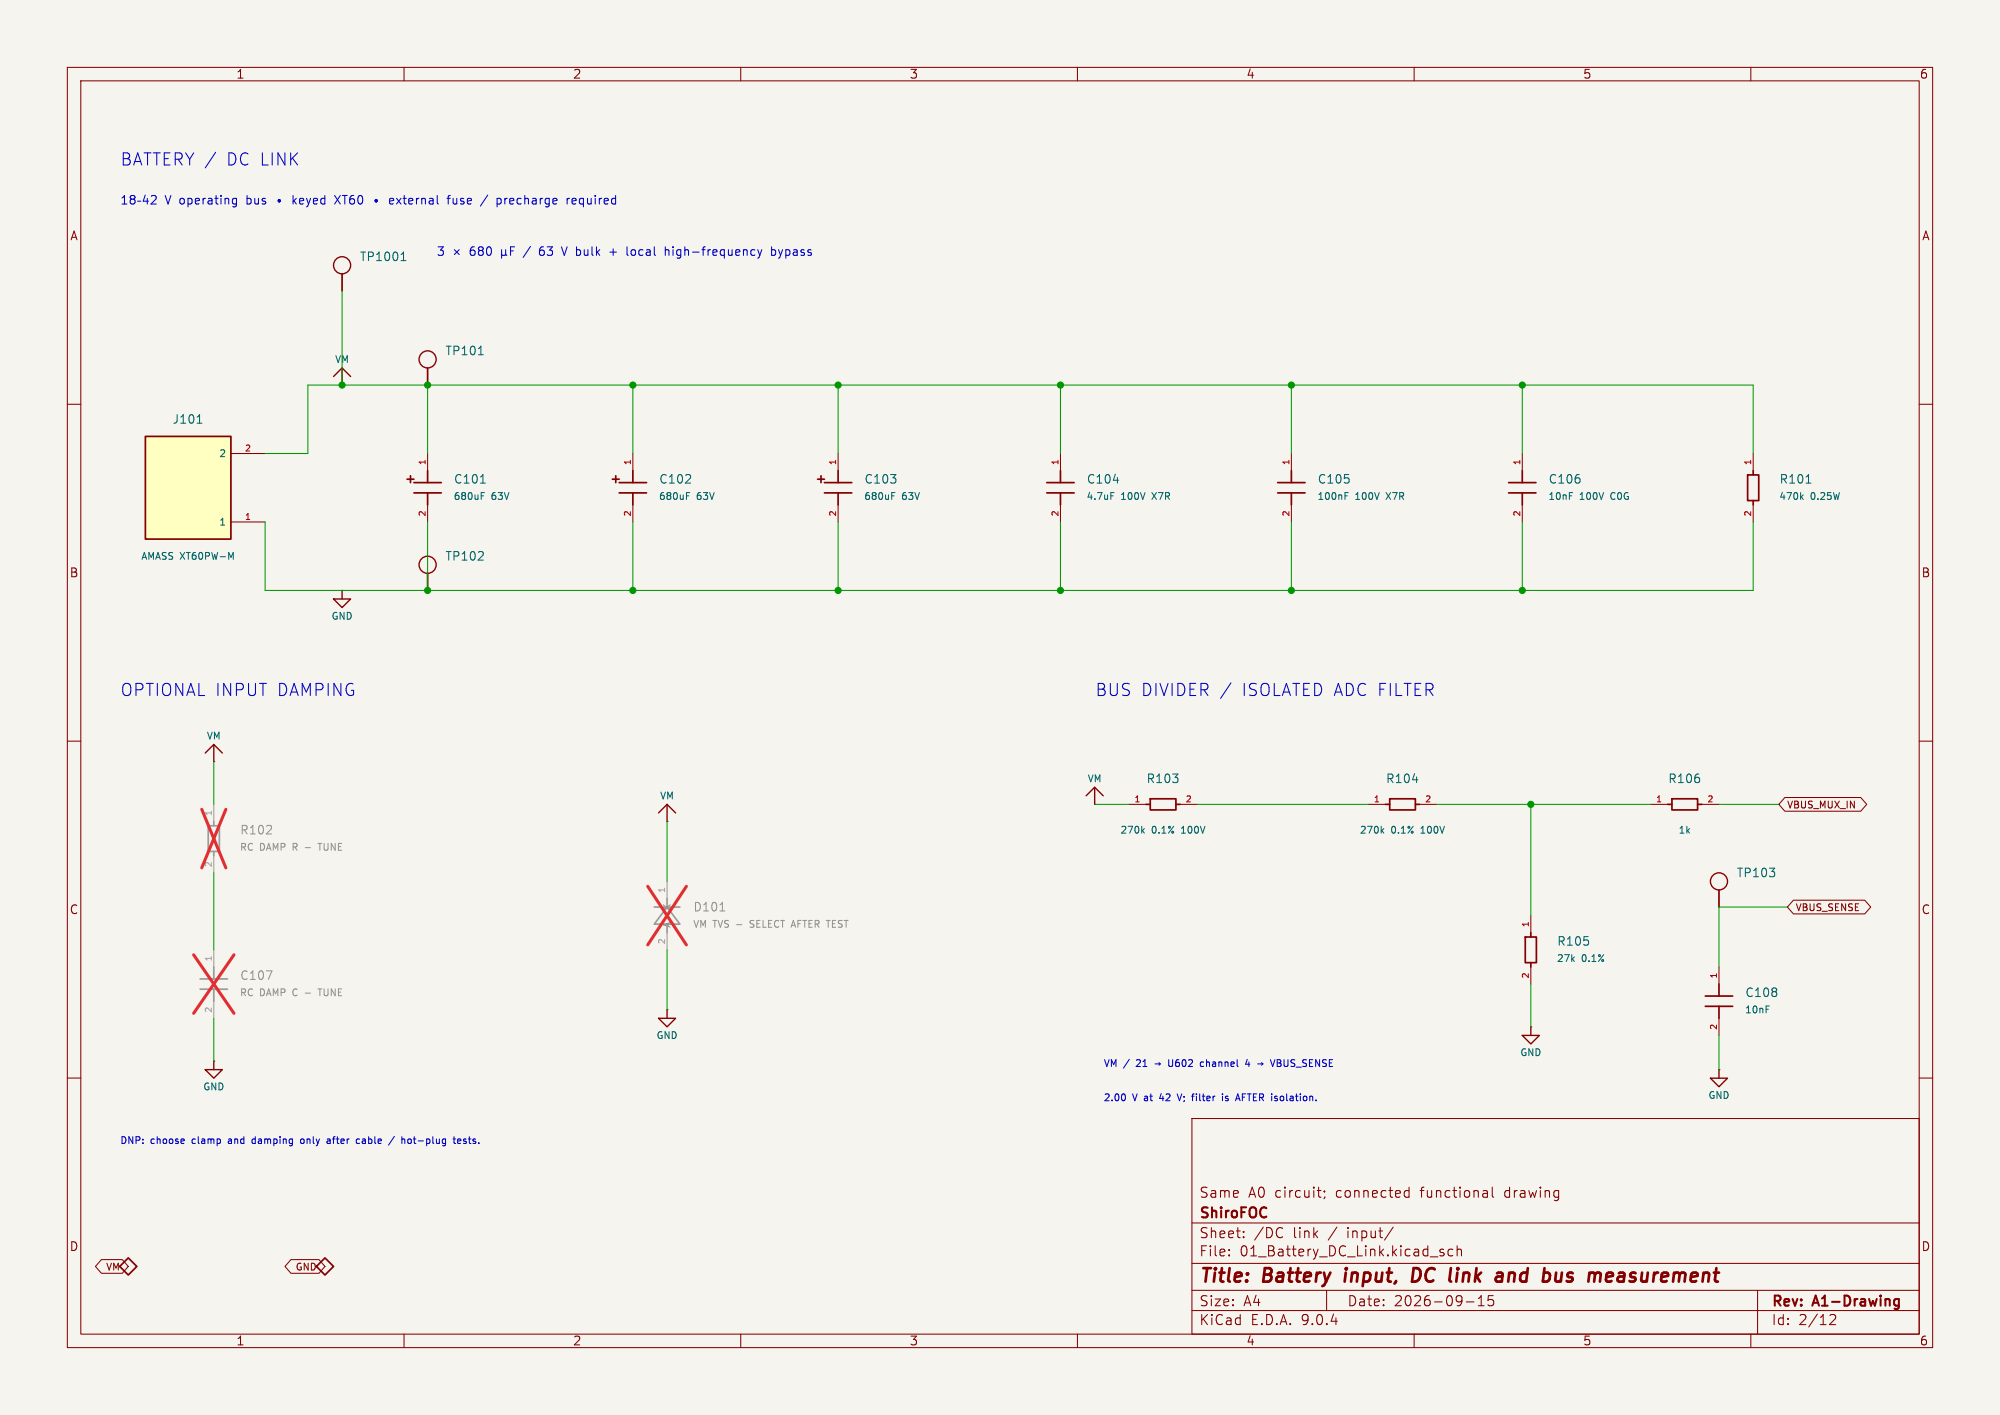
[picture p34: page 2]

VM TVS - SELECT AFTER TEST VM

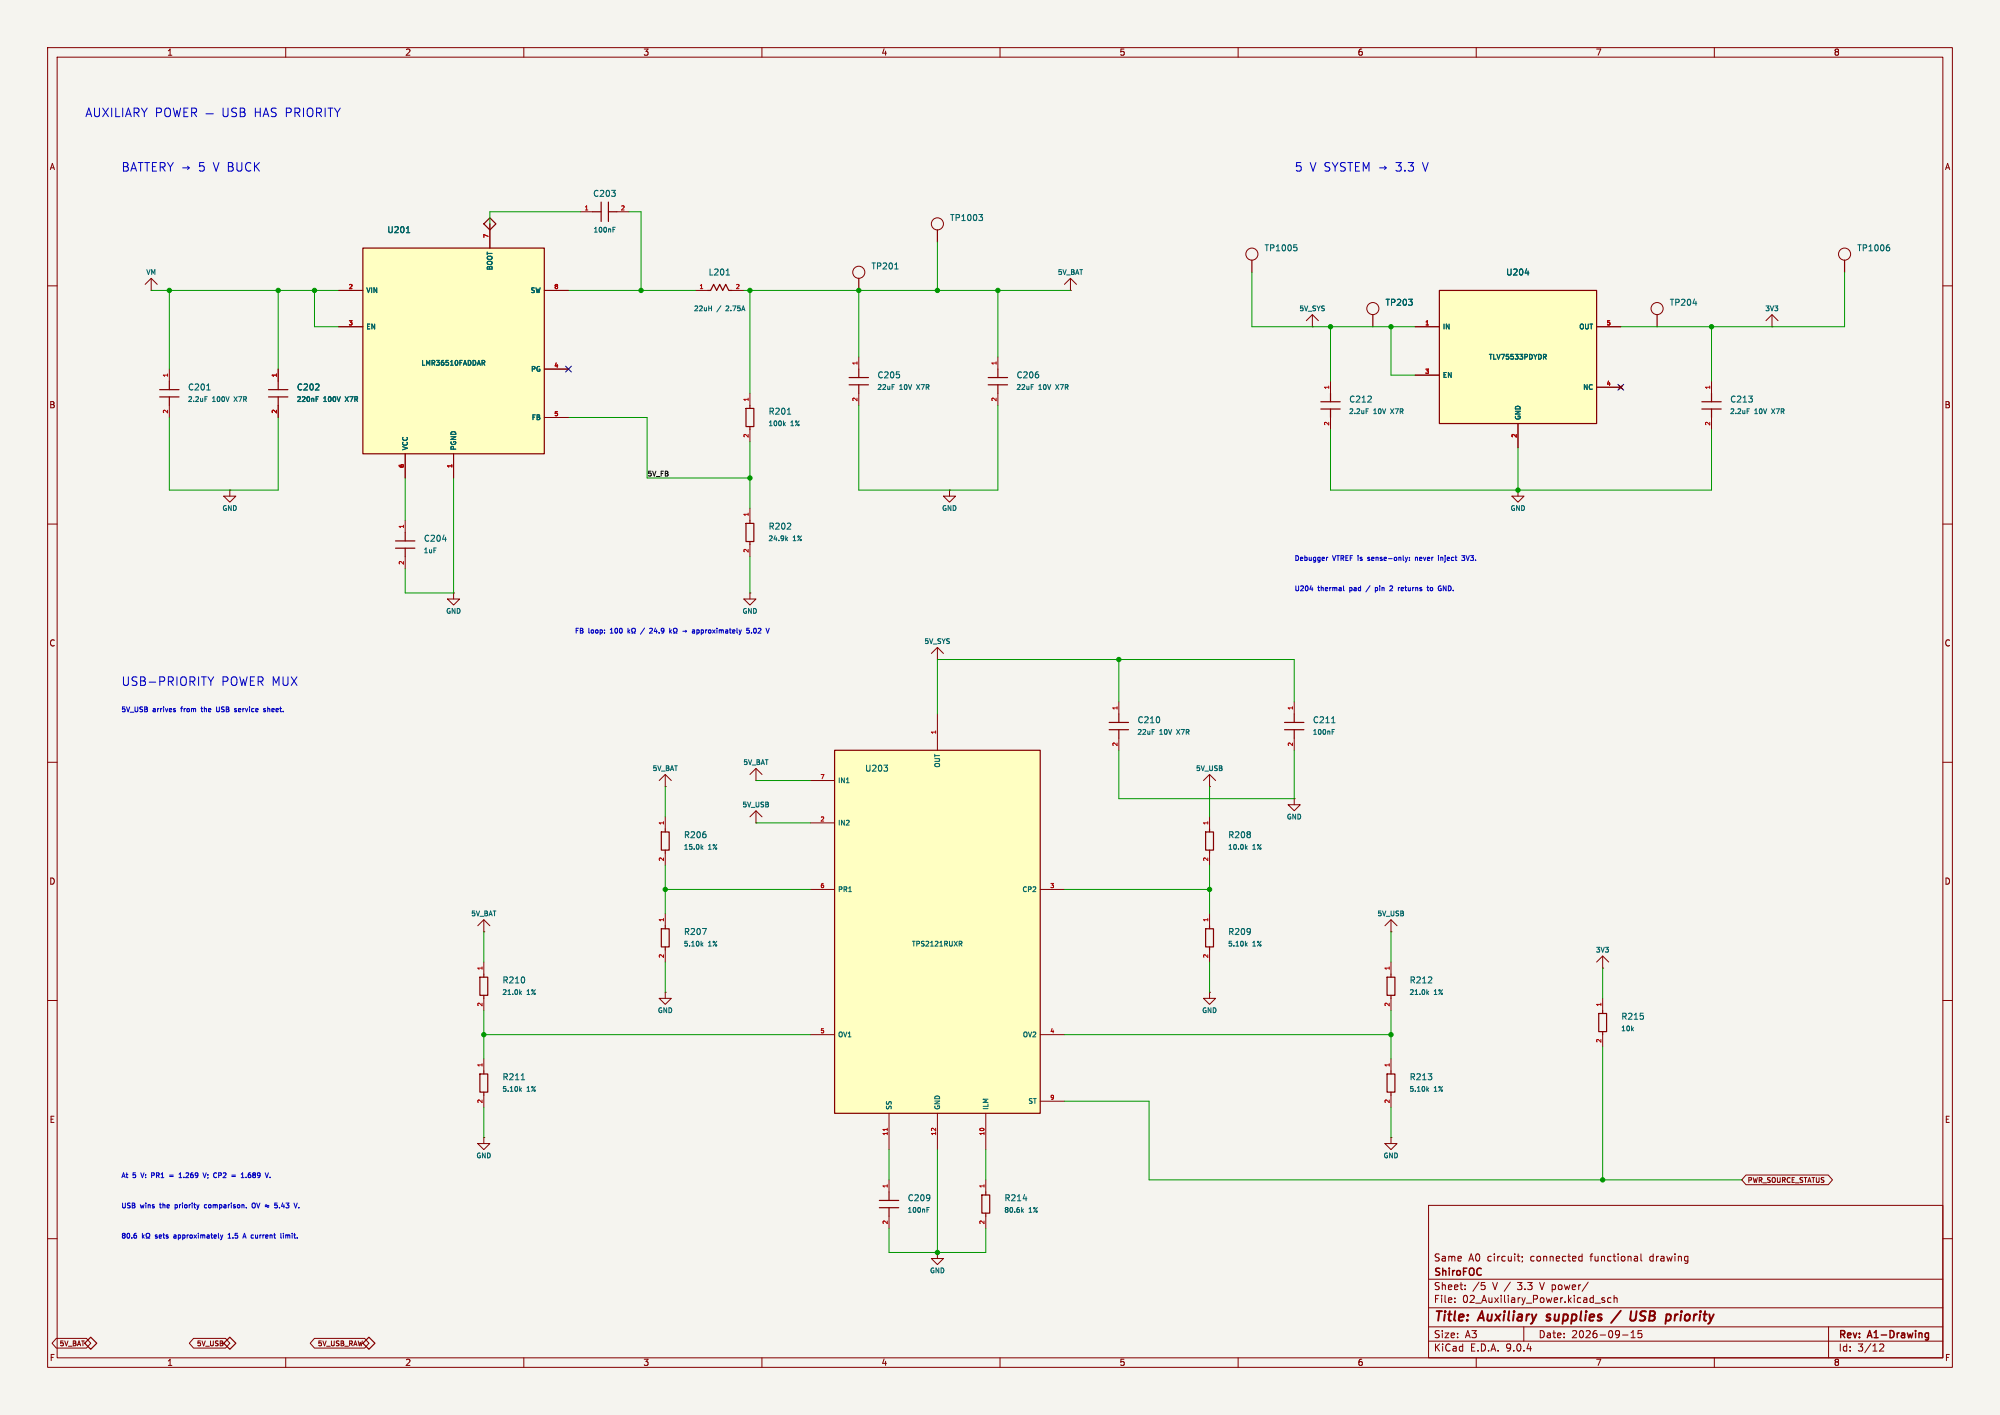
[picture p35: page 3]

5V_USB arrives from the USB service sheet. USB-PRIORITY POWER MUX

Id: 3/12 Title: Auxiliary supplies / USB priority

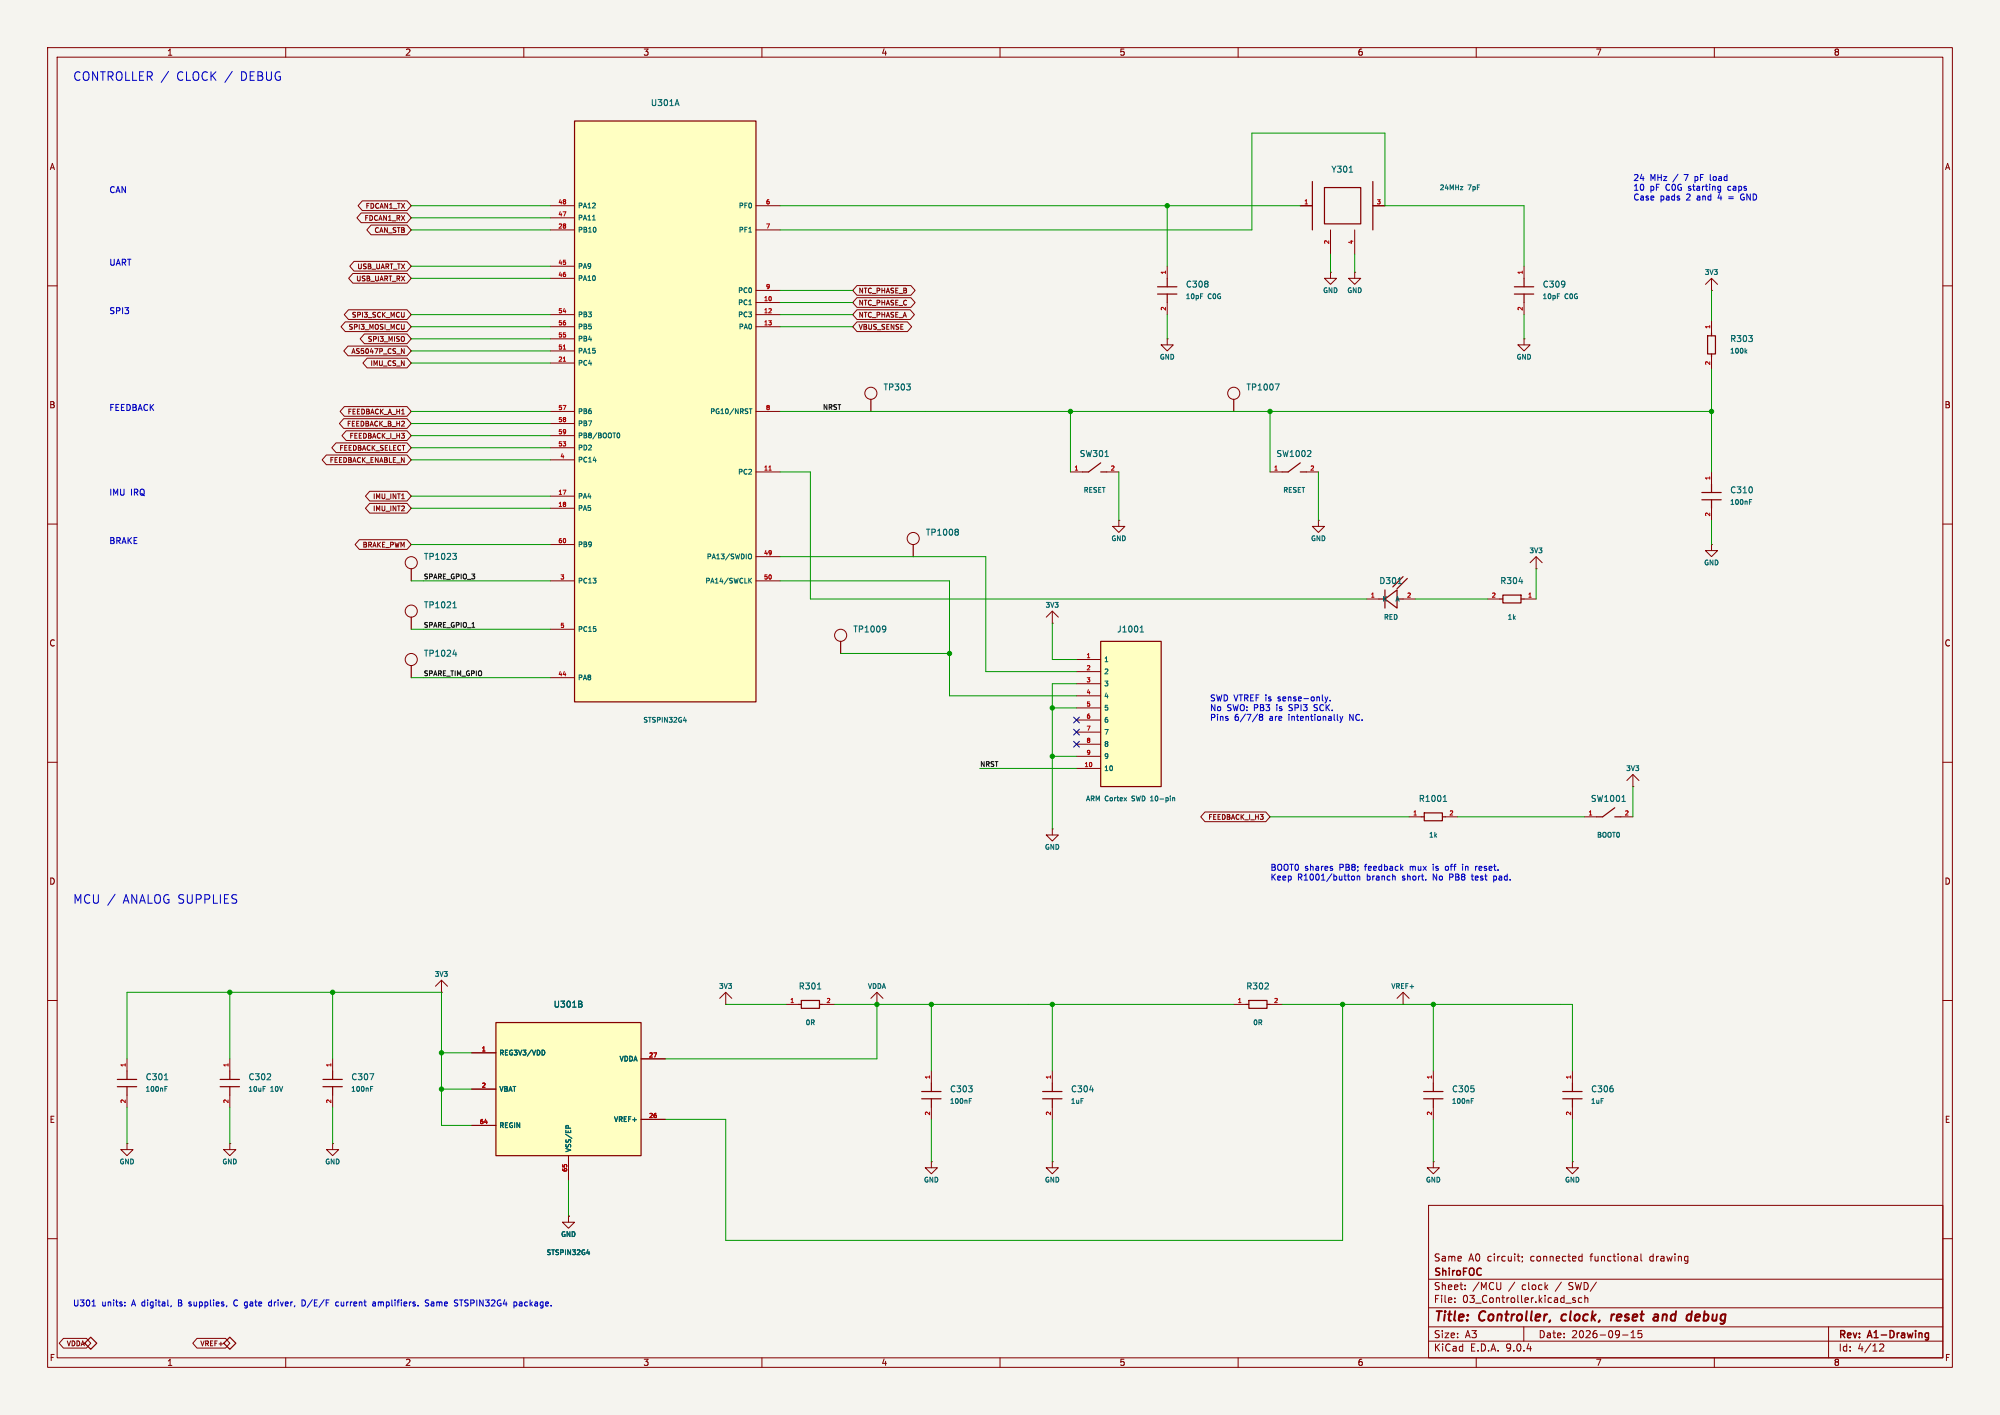
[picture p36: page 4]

UART CAN CONTROLLER / CLOCK / DEBUG

ARM Cortex SWD 10-pin

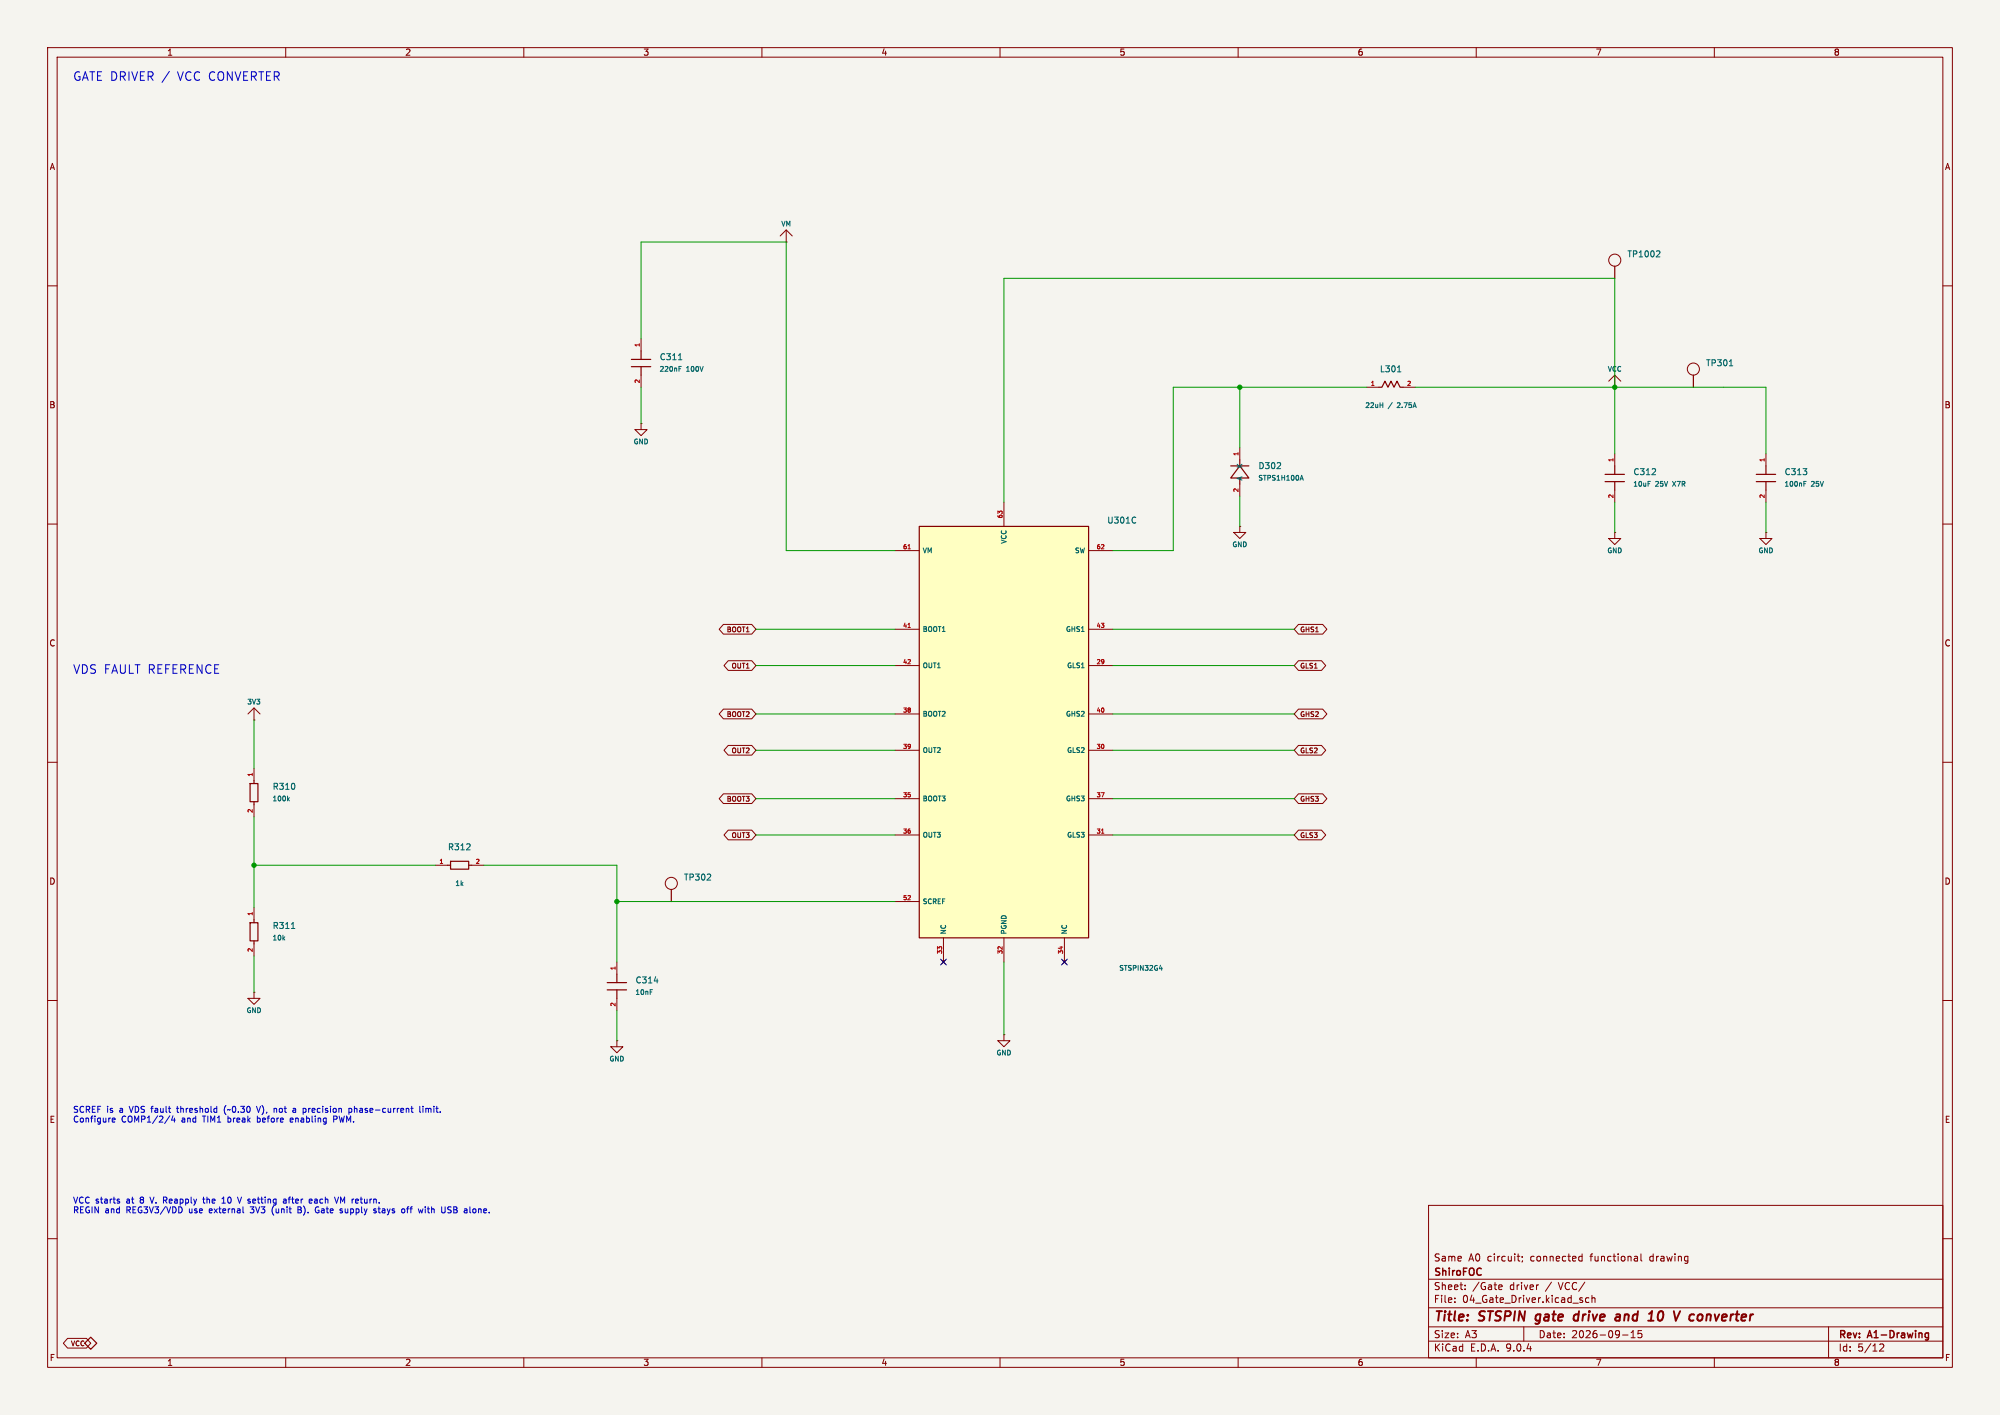
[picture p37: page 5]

GATE DRIVER / VCC CONVERTER

Id: 5/12 Title: STSPIN gate drive and 10 V converter File: 04_Gate_Driver.kicad_sch Sheet: /Gate driver / VCC/ ShiroFOC

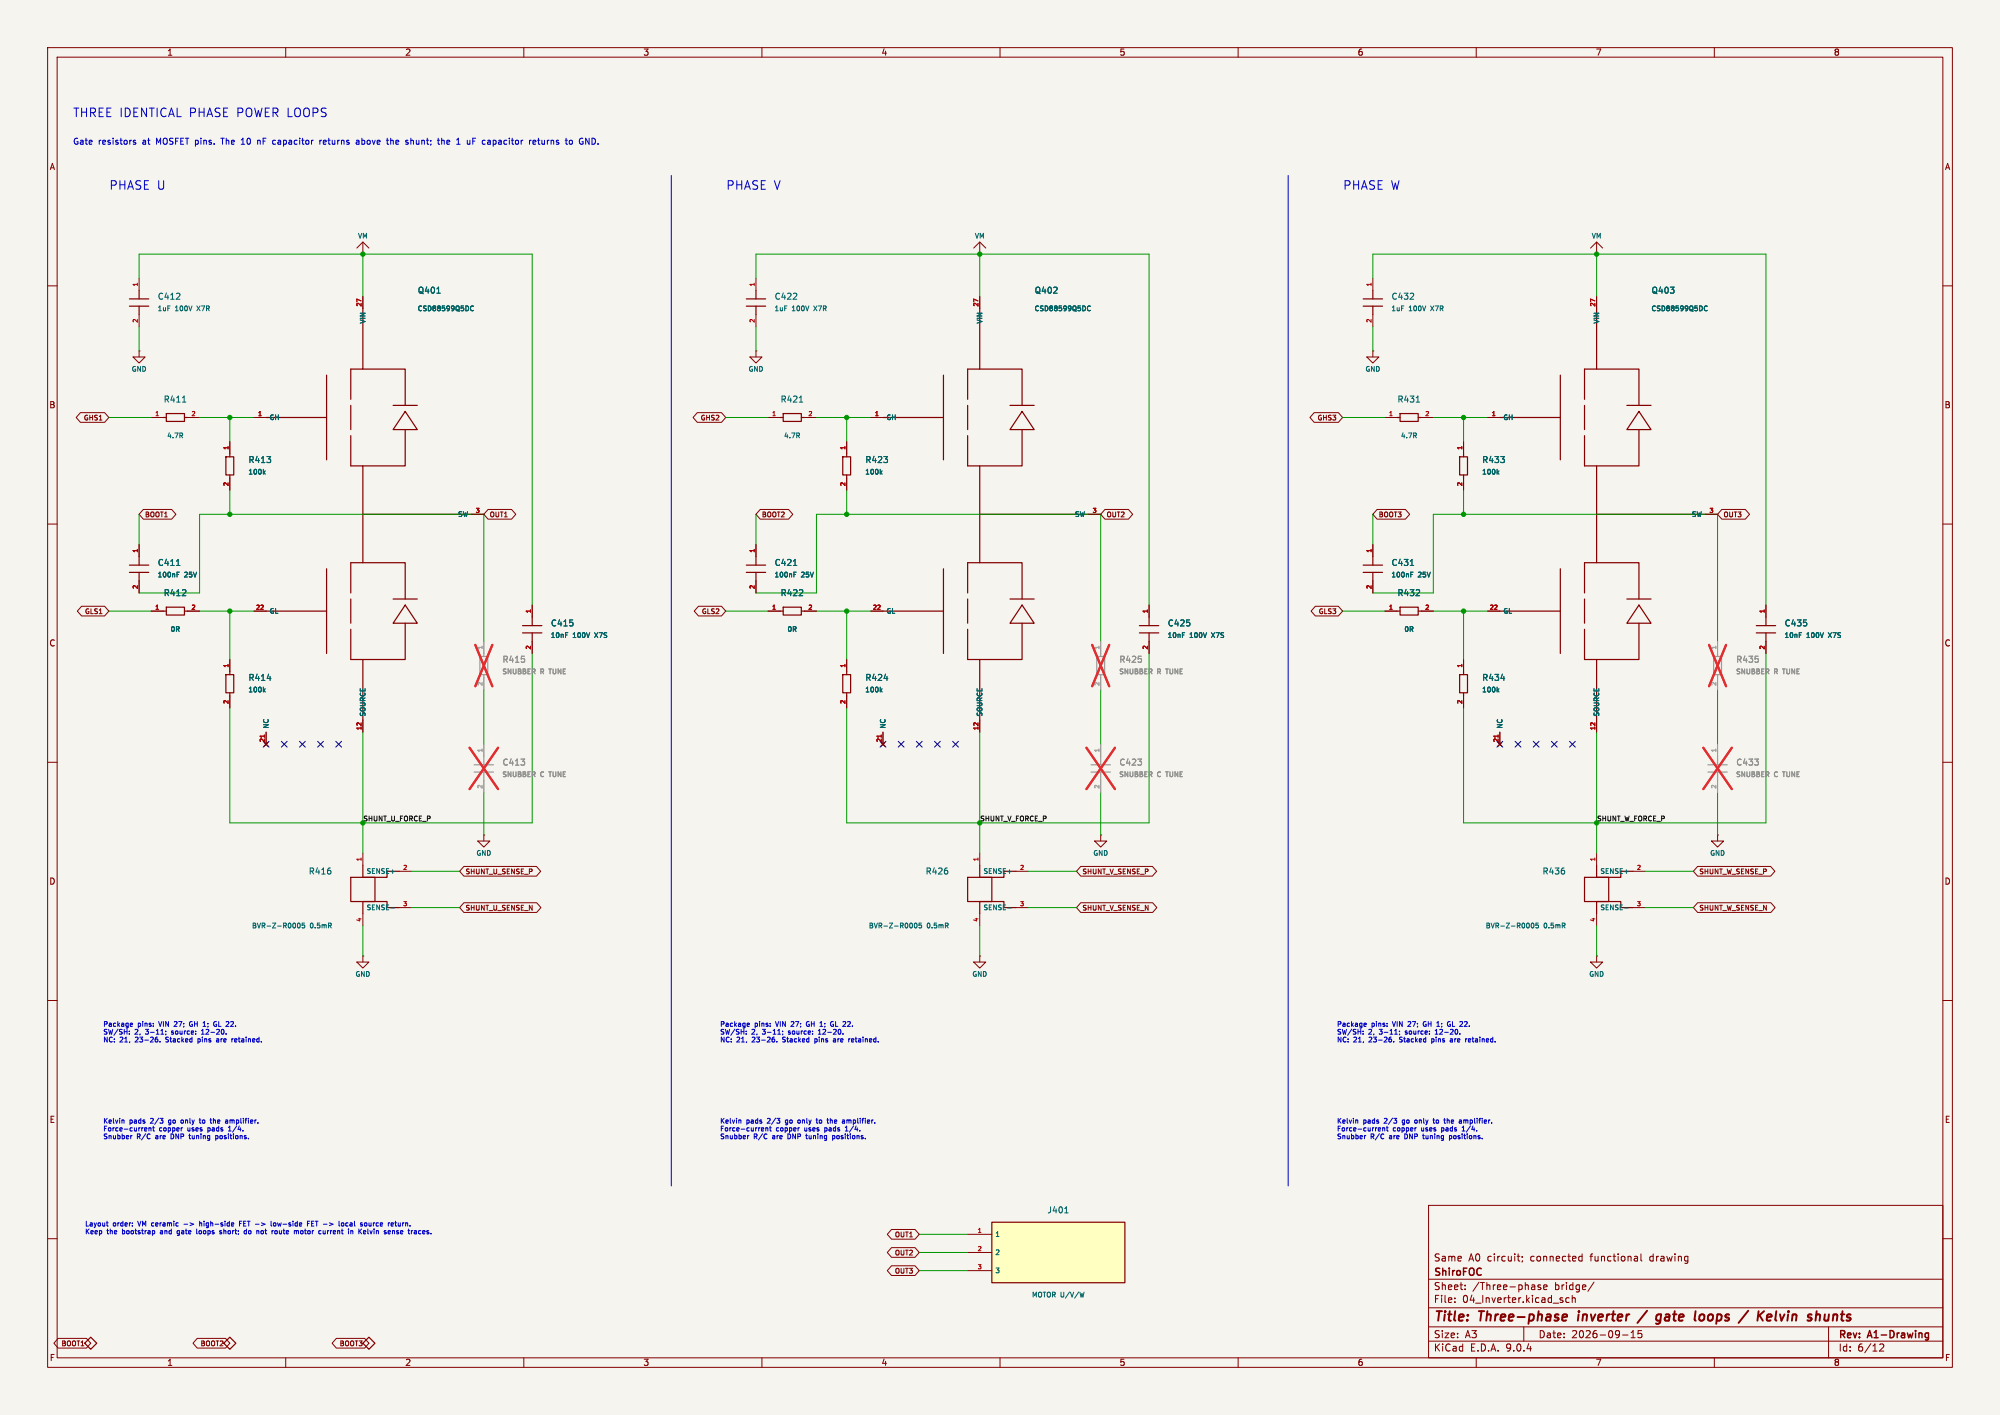
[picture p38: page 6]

THREE IDENTICAL PHASE POWER LOOPS

1 2 Q402 CSD88599Q5DC GH 1 GL 22 NC 21 VIN 27 SOURCE 12 SW 3 R424

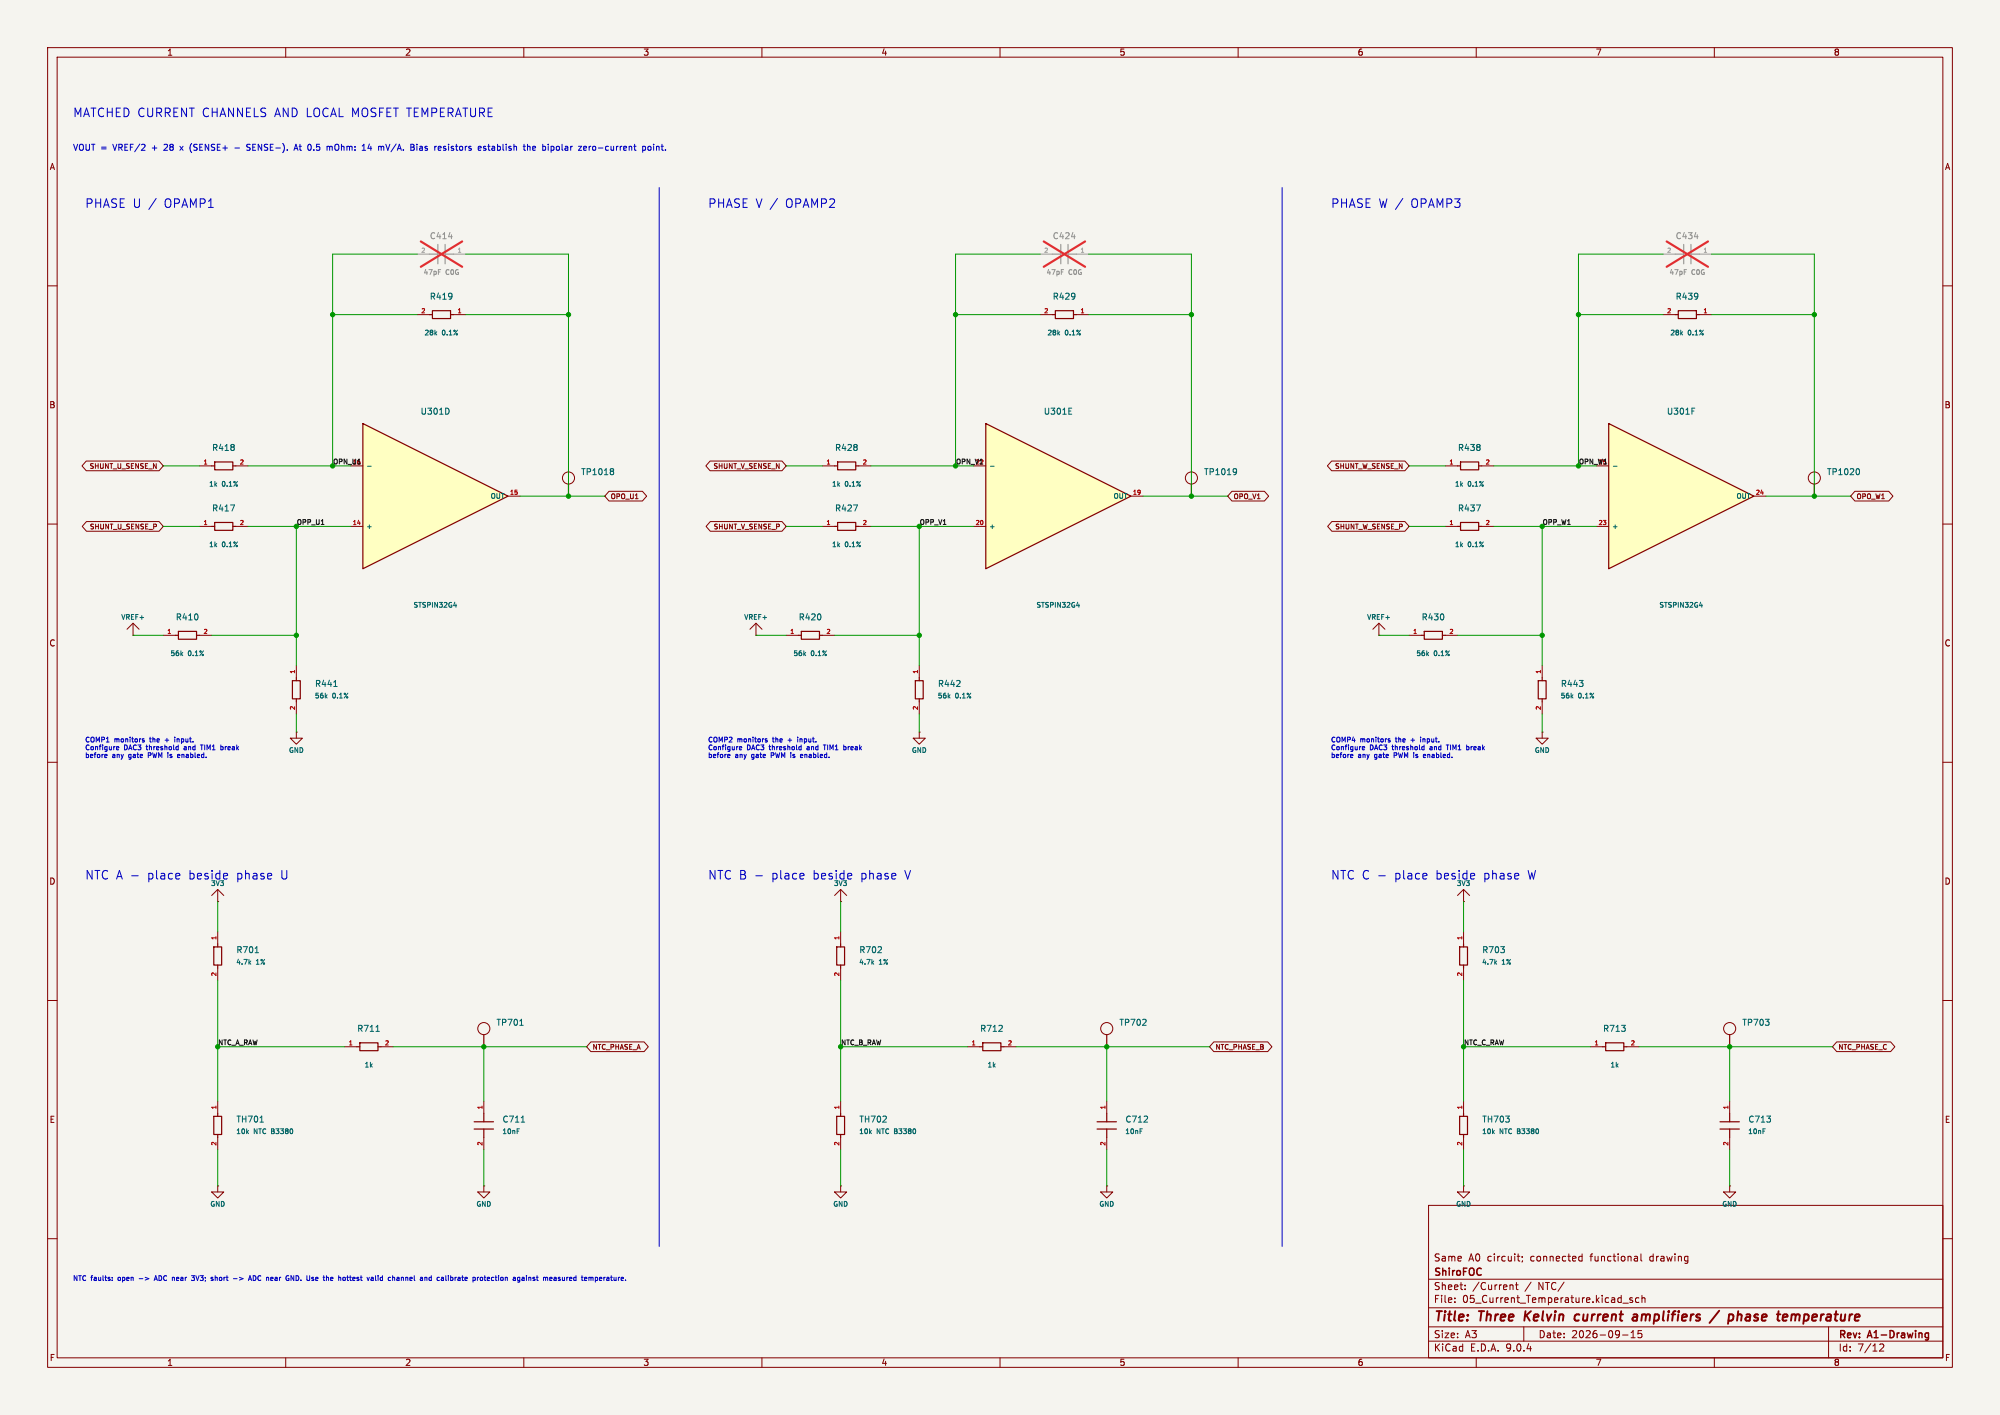
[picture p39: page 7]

MATCHED CURRENT CHANNELS AND LOCAL MOSFET TEMPERATURE

NTC C - place beside phase W

Id: 7/12 Title: Three Kelvin current amplifiers / phase temperature

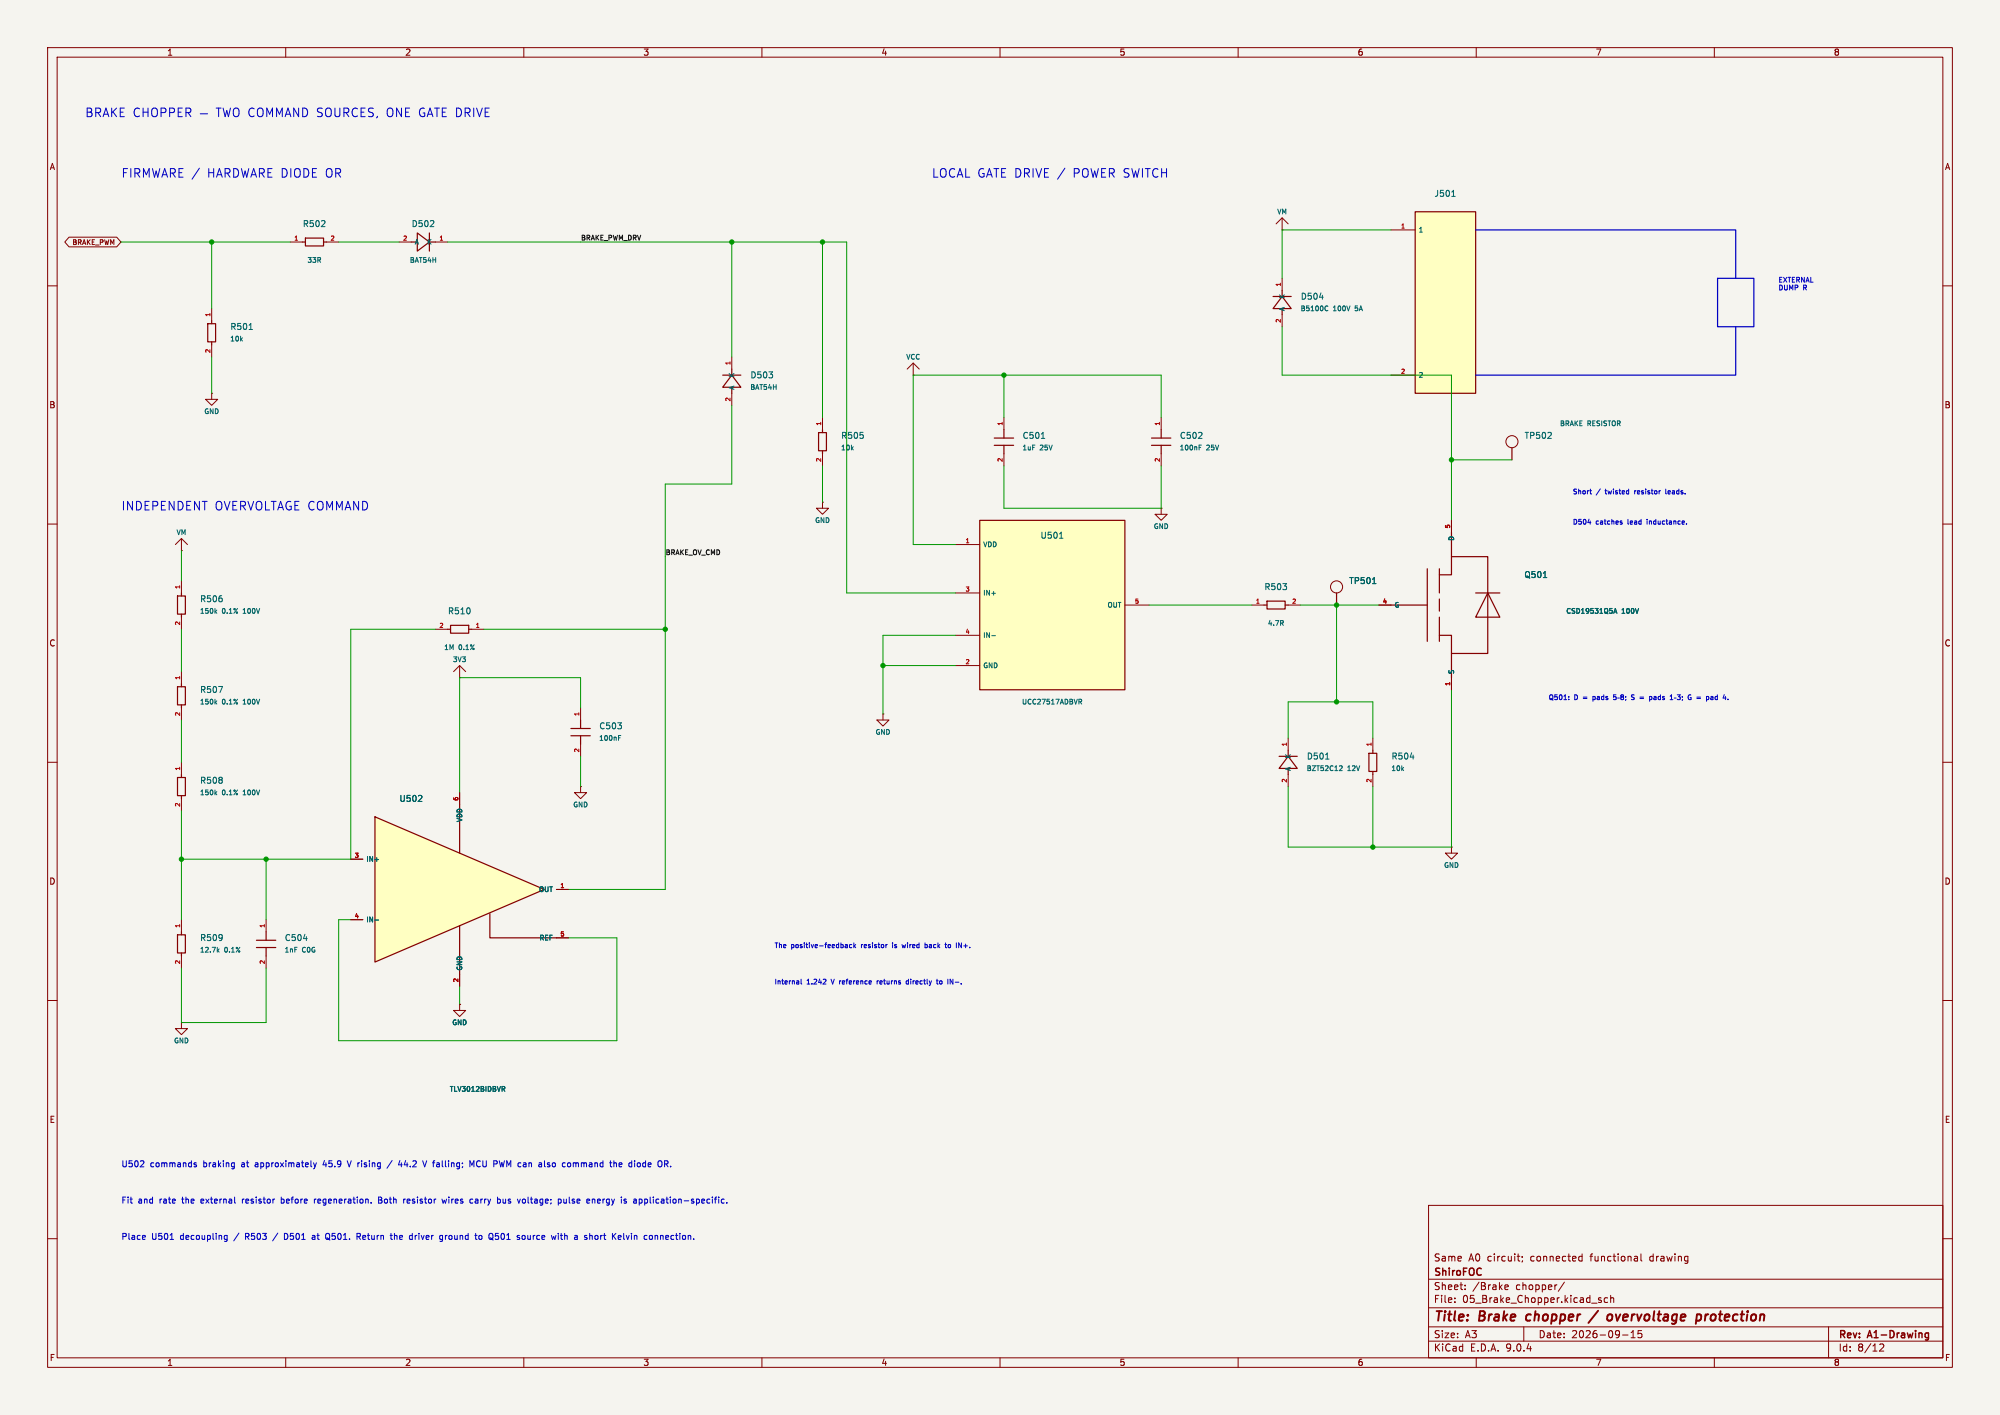
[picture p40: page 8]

BRAKE CHOPPER þÿ TWO COMMAND SOURCES, ONE GATE DRIVE

Id: 8/12 Title: Brake chopper / overvoltage protection

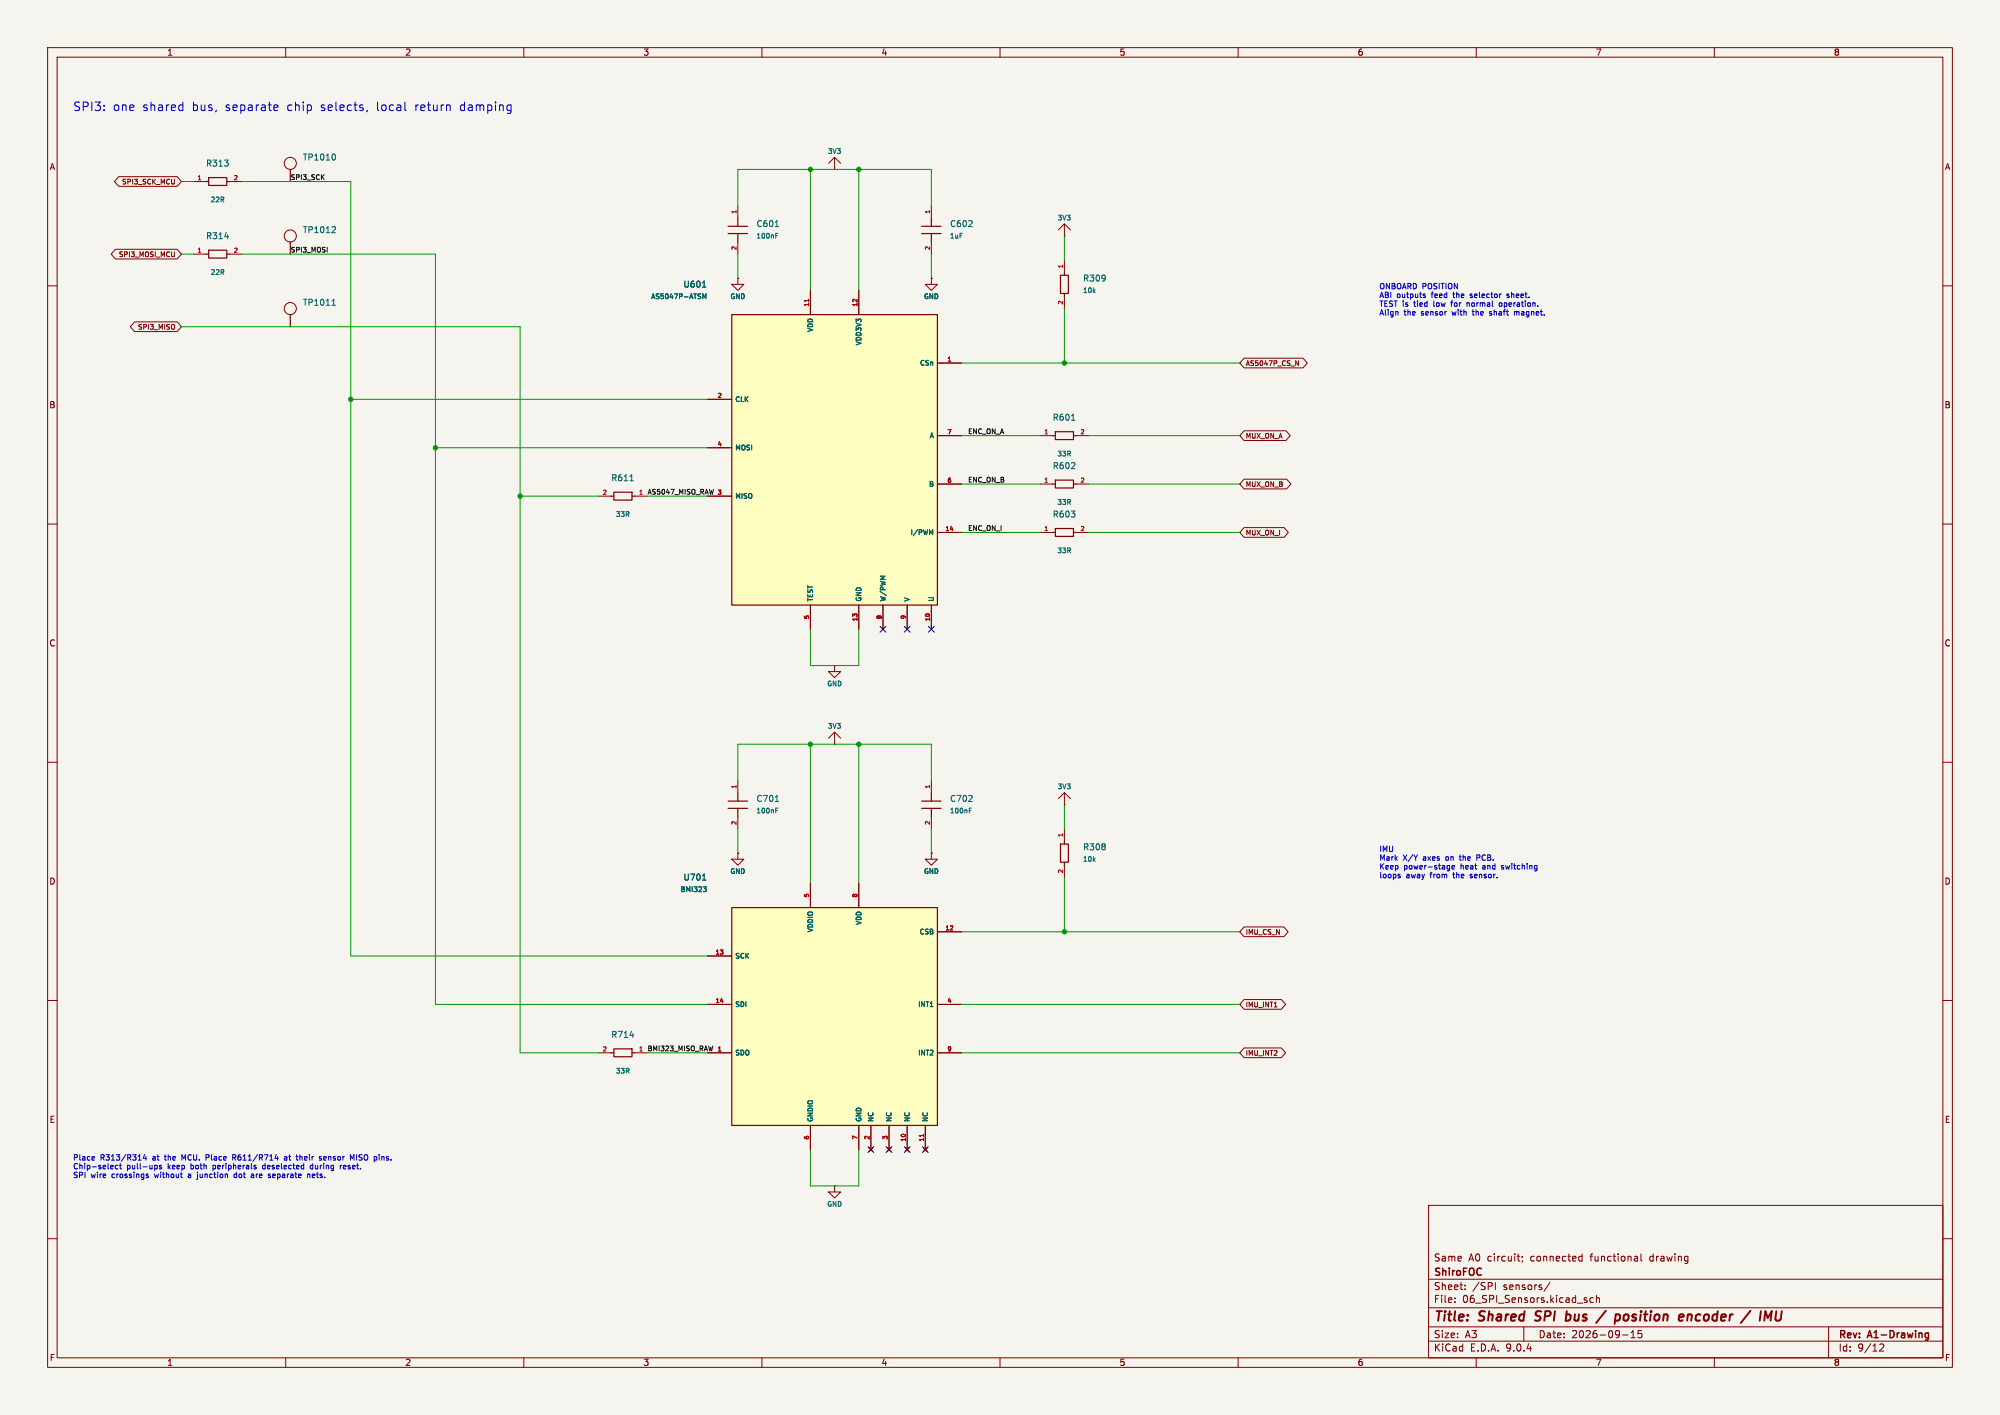
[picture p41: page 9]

SPI3: one shared bus, separate chip selects, local return damping

loops away from the sensor.

Id: 9/12 Title: Shared SPI bus / position encoder / IMU

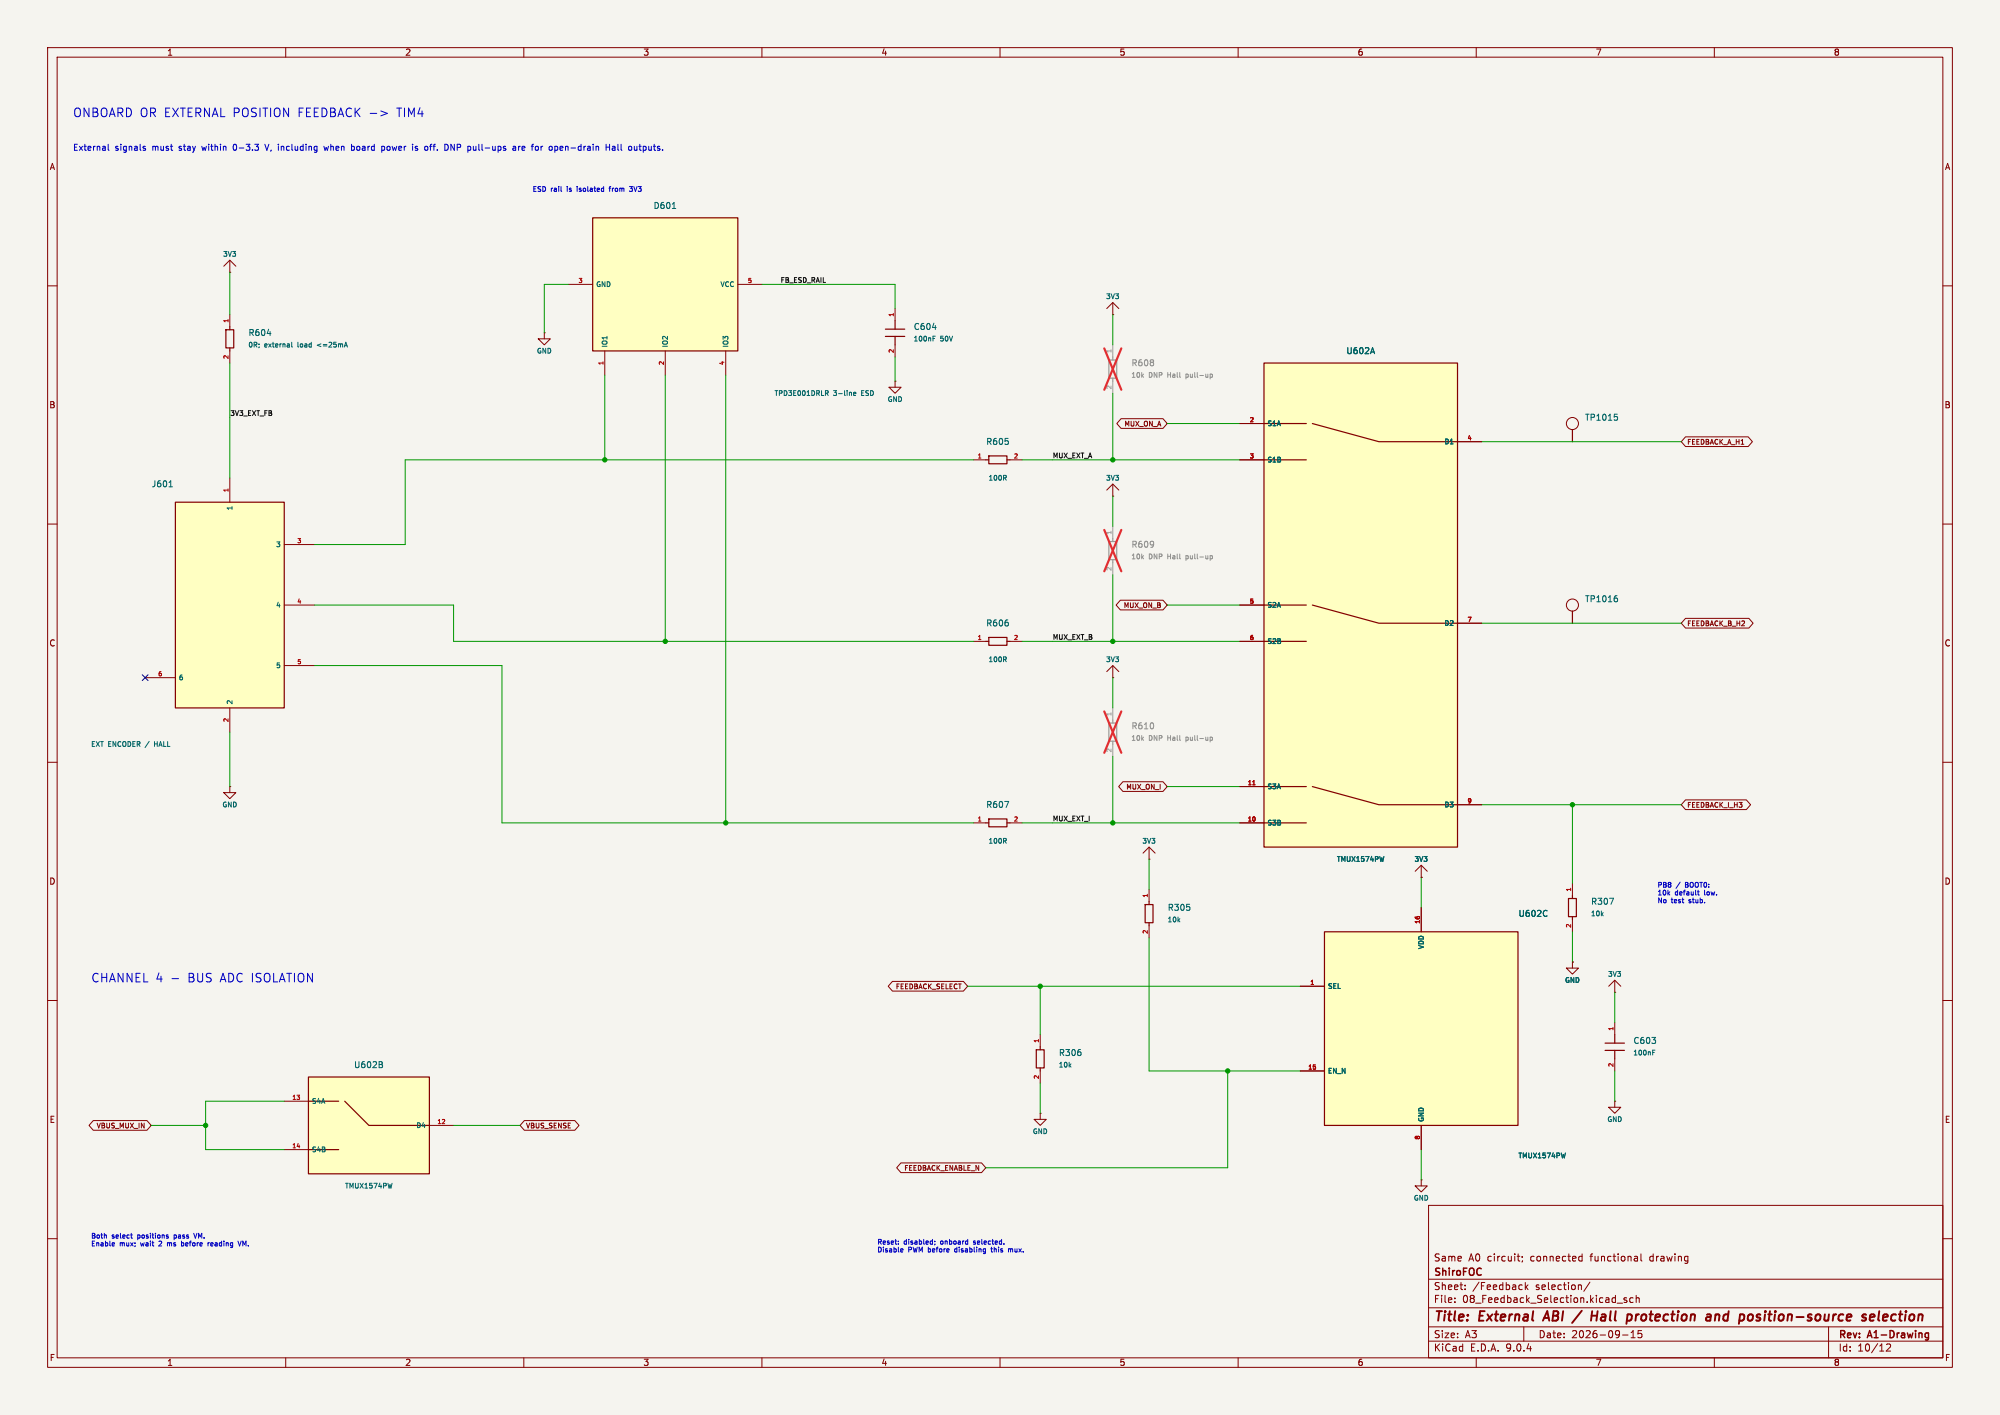
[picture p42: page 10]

10k DNP Hall pull-up

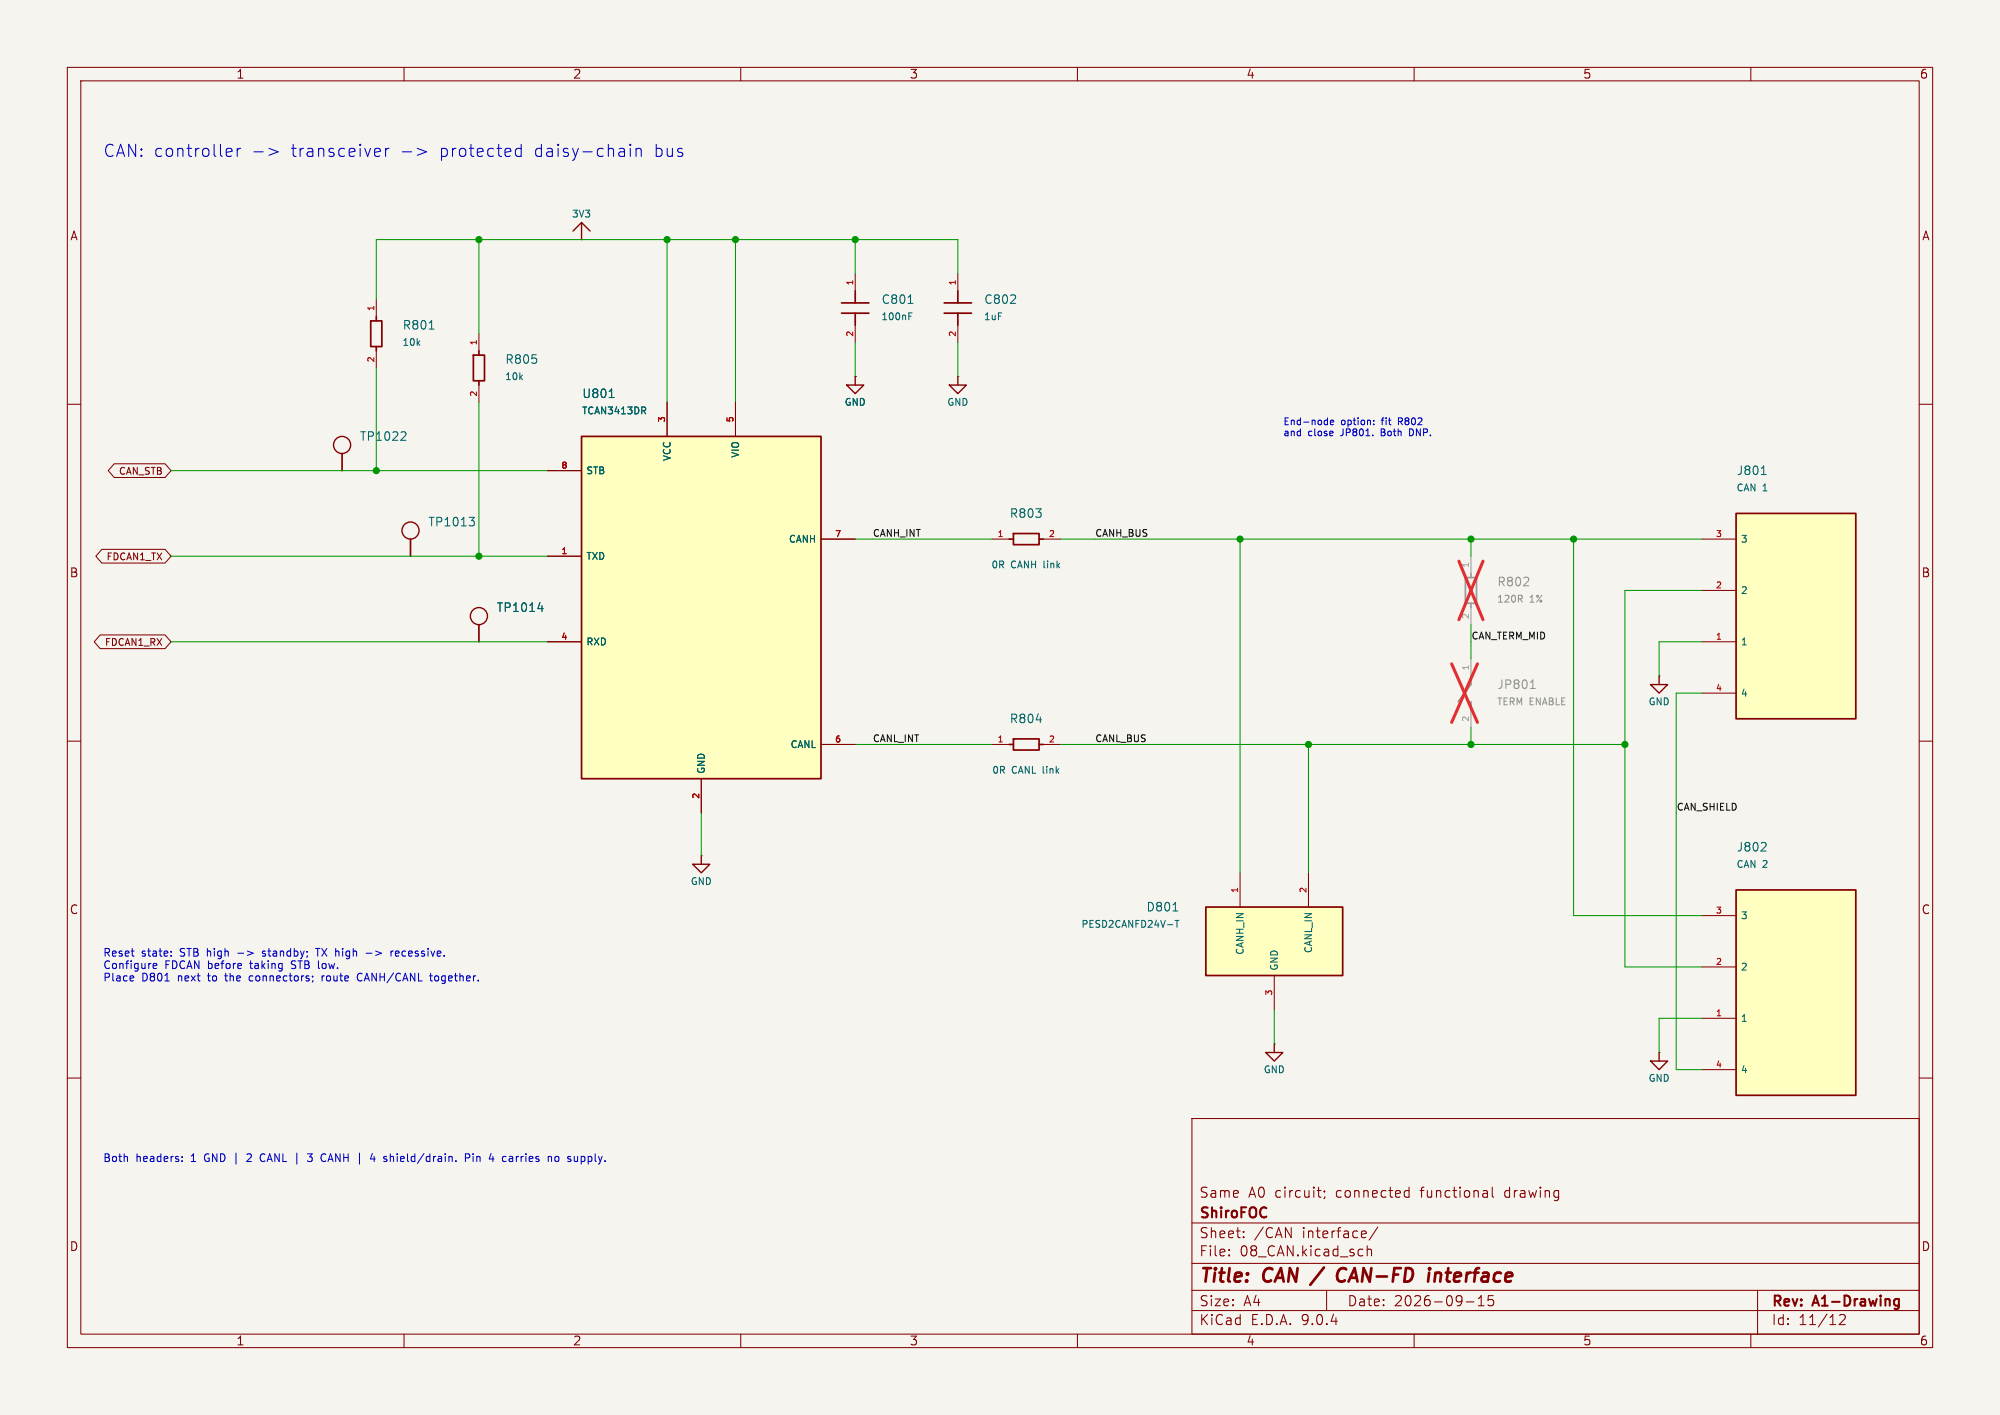
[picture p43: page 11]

Id: 11/12 Title: CAN / CAN-FD interface

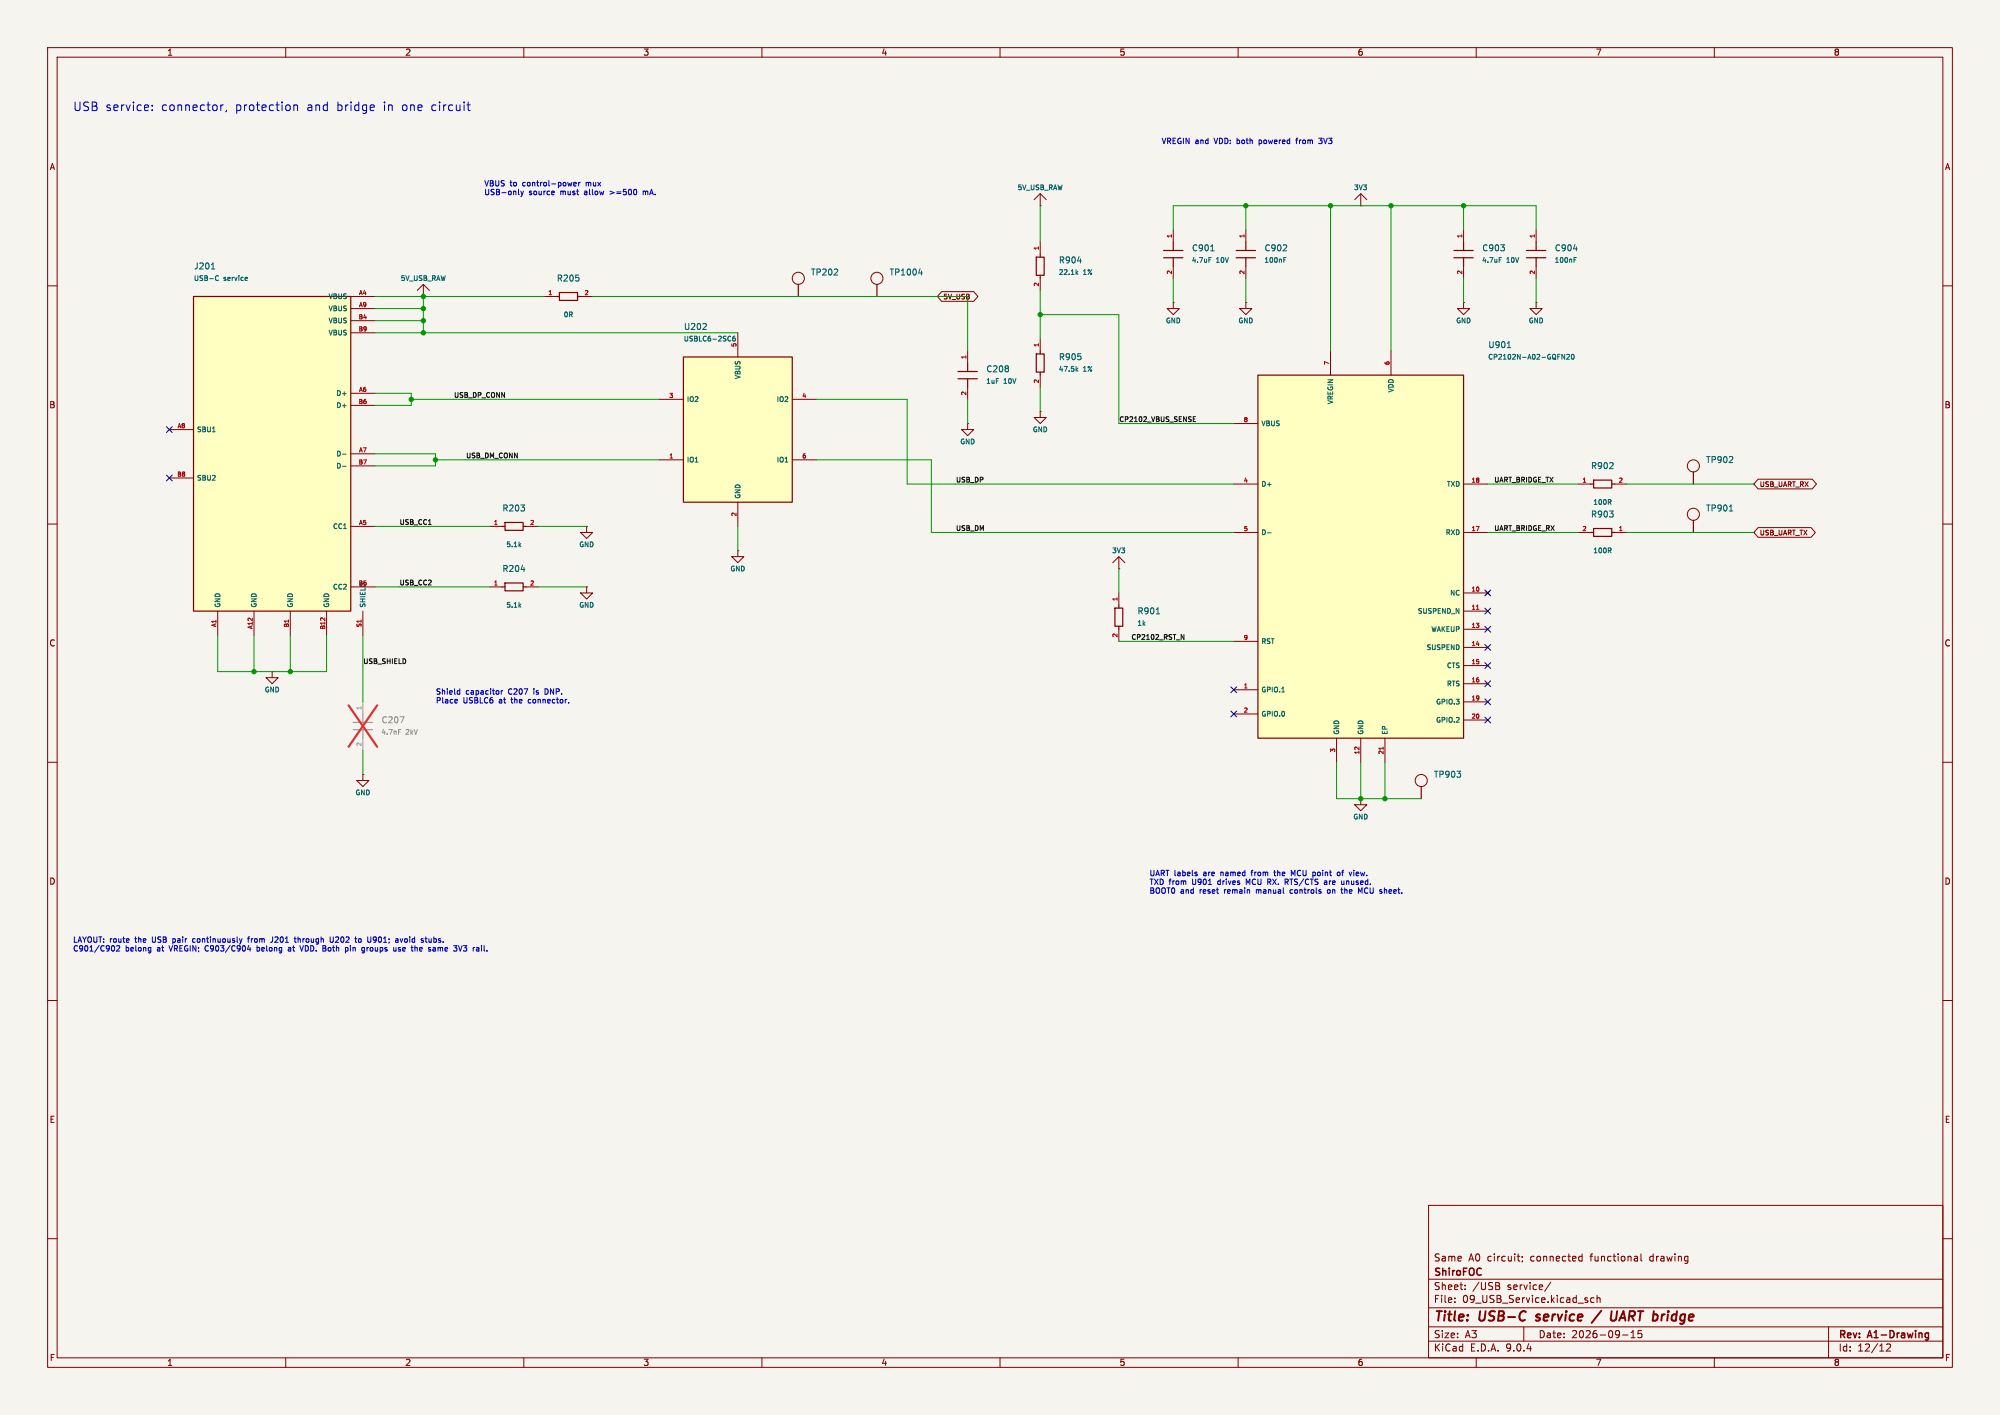
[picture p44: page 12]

VREGIN and VDD: both powered from 3V3

6 TXD 18 RXD 17 NC 10 SUSPEND_N 11 WAKEUP 13 SUSPEND 14 CTS 15 RTS 16 GPIO.3 19 GPIO.2 20 U901 CP2102N-A02-GQFN20

Id: 12/12 Title: USB-C service / UART bridge

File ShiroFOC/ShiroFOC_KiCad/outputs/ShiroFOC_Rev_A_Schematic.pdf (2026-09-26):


ShiroFOC - CONNECTED FUNCTIONAL SCHEMATIC

USB-C / UART bridge Sheet 9

Driver control Gate driver / VCC

File: ShiroFOC_KiCad.kicad_sch Sheet: /
Id: 1/12 Title: ShiroFOC A1 - connected functional overview


2 D101 VM TVS - SELECT AFTER TEST


AUXILIARY POWER - USB HAS PRIORITY

5V_USB arrives from the USB service sheet.

Id: 3/12 Title: Auxiliary supplies / USB priority


UART CAN CONTROLLER / CLOCK / DEBUG


GATE DRIVER / VCC CONVERTER

Id: 5/12 Title: STSPIN gate drive and 10 V converter File: 04_Gate_Driver.kicad_sch Sheet: /Gate driver / VCC/ ShiroFOC


THREE IDENTICAL PHASE POWER LOOPS


NTC C - place beside phase W

Id: 7/12 Title: Three Kelvin current amplifiers / phase temperature


BRAKE CHOPPER - TWO COMMAND SOURCES, ONE GATE DRIVE

FIRMWARE / HARDWARE DIODE OR

LOCAL GATE DRIVE / POWER SWITCH

Id: 8/12 Title: Brake chopper / overvoltage protection


SPI3: one shared bus, separate chip selects, local return damping

loops away from the sensor.

Id: 9/12 Title: Shared SPI bus / position encoder / IMU


10k DNP Hall pull-up


Id: 11/12 Title: CAN / CAN-FD interface


6 TXD 18 RXD 17 NC 10 SUSPEND_N 11 WAKEUP 13 SUSPEND 14 CTS 15 RTS 16 GPIO.3 19 GPIO.2 20 U901 CP2102N-A02-GQFN20

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

Id: 12/12 Title: USB-C service / UART bridge

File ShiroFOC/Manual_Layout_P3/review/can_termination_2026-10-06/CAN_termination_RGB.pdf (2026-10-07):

1 | 2 | 3 | 4 | 5 | 6 | 7 | 8

A


CANL_BUS CANH_BUS SOFTWARE-CONTROLLED 120 OHM TERMINATION

Id: 11/12 Title: CAN / CAN-FD interface

1 | 2 | 3 | 4 | 5 | 6 | 7 | 8

A


CONTROLLER / CLOCK / DEBUG
UART CAN MCU / ANALOG SUPPLIES

POWER / CAN TERMINATION INDICATOR

5 ~{RESET}3 SWCLK 4 SWDIO 2 SWO 6

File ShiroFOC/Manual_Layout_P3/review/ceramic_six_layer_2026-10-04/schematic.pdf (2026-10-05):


UART Sheet 12 USB-C / UART bridge USB service

SPI3 angle + I2C2 motion Encoder / IMU

File: ShiroFOC_Manual.kicad_sch Sheet: /
Id: 1/12 Title: ShiroFOC - connected functional overview


2 D101 VM TVS - SELECT AFTER TEST


AUXILIARY POWER - USB HAS PRIORITY

FB: 100 þÿk©/ 11.1 þÿk©þÿ!’10.01 V BATTERY þÿ!’10 V BUCK

Id: 3/12 Title: 10 V / 5 V / 3.3 V auxiliary supplies


UART CONTROLLER / CLOCK / DEBUG

5 ~{RESET}3 SWCLK 4 SWDIO 2 SWO 6


GATE DRIVER / EXTERNAL 10 V SUPPLY

INTERNAL BUCK BYPASSED: SW þÿ!’VM

File: 04_Gate_Driver.kicad_sch Sheet: /Gate driver / VCC/ ShiroFOC

Id: 5/12 Title: STSPIN gate driver / external 10 V


TP422 SOURCE C423 TUNE DNP R425 TUNE DNP GND


MATCHED CURRENT CHANNELS AND LOCAL MOSFET TEMPERATURE

Id: 7/12 Title: Three Kelvin current amplifiers / phase temperature


BRAKE CHOPPER - TWO COMMAND SOURCES, ONE GATE DRIVE

FIRMWARE / HARDWARE DIODE OR

LOCAL GATE DRIVE / POWER SWITCH

Id: 8/12 Title: Brake chopper / overvoltage protection


Id: 9/12 Title: Absolute encoder SPI / IMU I2C


1 2 GND GND GND GND R610

Id: 10/12 Title: External Hall / ABI conditioning and reset isolation


Id: 11/12 Title: CAN / CAN-FD interface


6 TXD 18 RXD 17 NC 10 SUSPEND_N 11 WAKEUP 13 SUSPEND 14 CTS 15 RTS 16 GPIO.3 19 GPIO.2 20U901 CP2102N-A02-GQFN20

6 TXD 18 RXD 17 NC 10 SUSPEND_N 11 WAKEUP 13 SUSPEND 14 CTS 15 RTS 16 GPIO.3 19 GPIO.2 20

Id: 12/12 Title: USB-C service / UART bridge

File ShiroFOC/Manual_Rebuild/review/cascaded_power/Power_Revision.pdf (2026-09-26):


Sheet 9 VM distribution Sheet 2

File: ShiroFOC_Manual.kicad_sch Sheet: /
Id: 1/12 Title: ShiroFOC - connected functional overview


AUXILIARY POWER - USB HAS PRIORITY

USB-PRIORITY POWER MUX

5V_USB arrives from the USB service sheet.

Id: 3/12 Title: 10 V / 5 V / 3.3 V auxiliary supplies


GATE DRIVER / EXTERNAL 10 V SUPPLY

INTERNAL BUCK BYPASSED: SW þÿ!’VM

Keep 10 uF + 100 nF beside VCC / PGND.

File: 04_Gate_Driver.kicad_sch Sheet: /Gate driver / VCC/ ShiroFOC

Id: 5/12 Title: STSPIN gate driver / external 10 V

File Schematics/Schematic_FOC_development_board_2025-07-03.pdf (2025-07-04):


Drawn By: Dion Lavaleije

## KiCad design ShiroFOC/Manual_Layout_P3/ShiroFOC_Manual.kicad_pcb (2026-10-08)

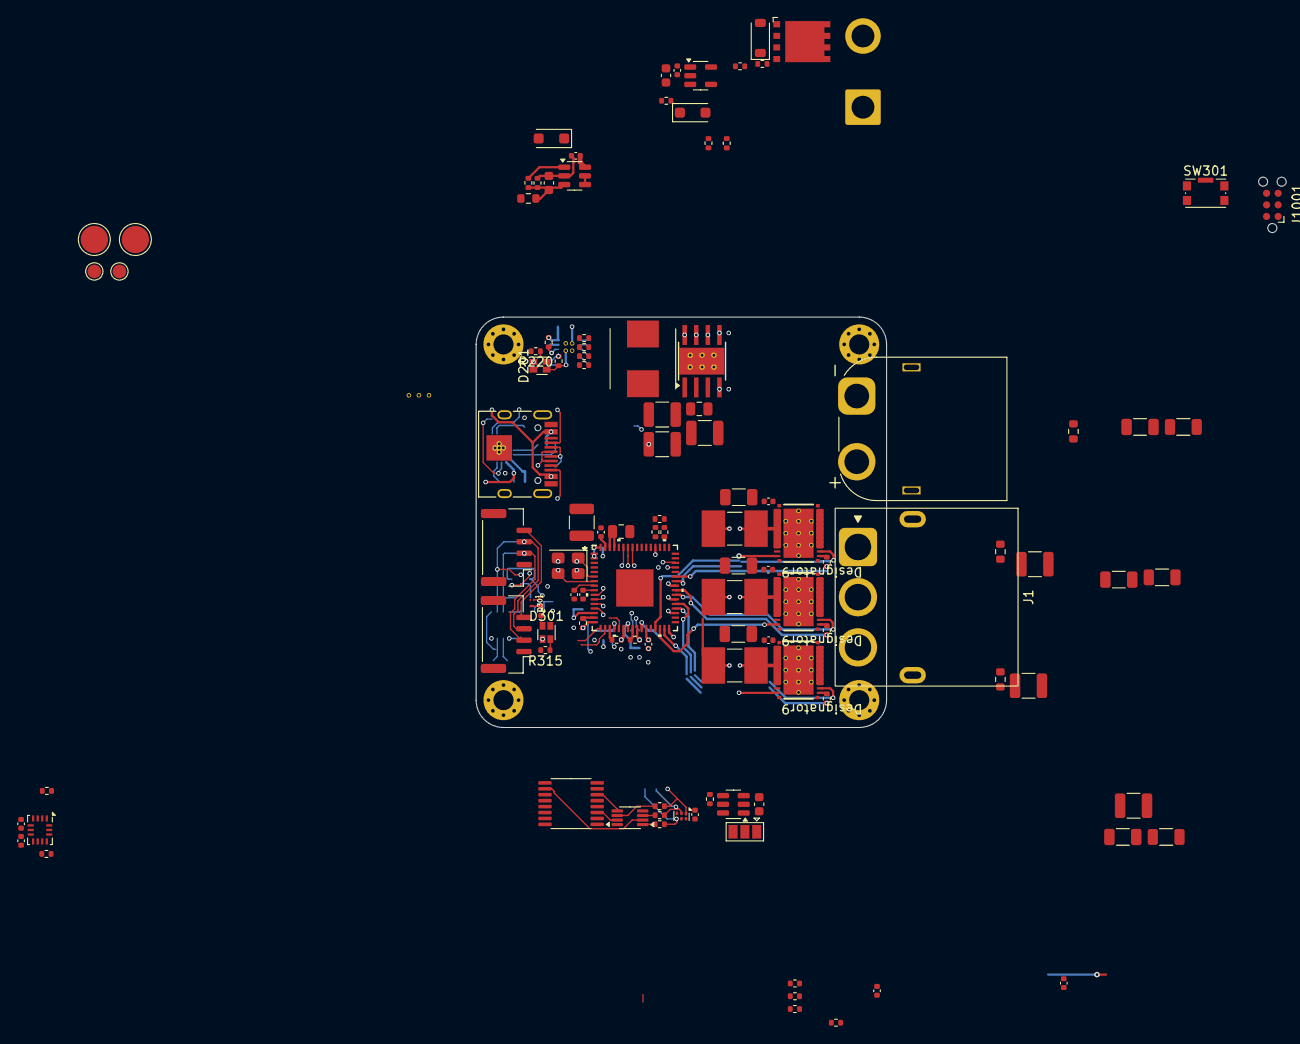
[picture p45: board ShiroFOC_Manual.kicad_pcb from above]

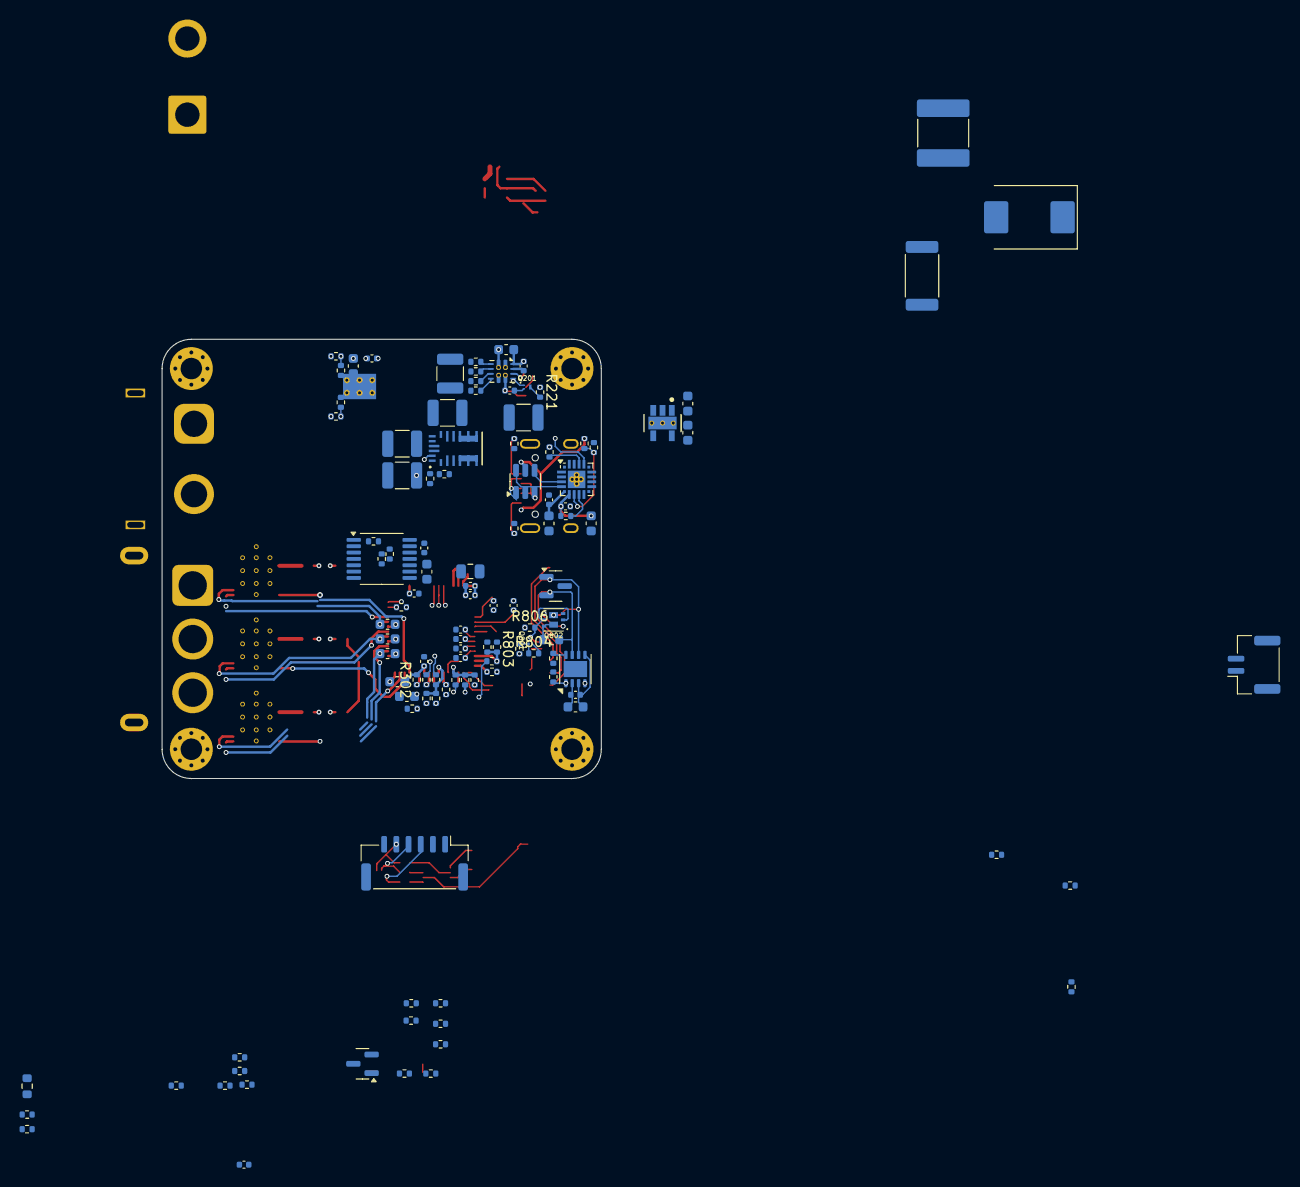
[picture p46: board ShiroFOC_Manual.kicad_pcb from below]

Board: 6 copper layers, 45.0 x 45.0 mm, 228 parts (113 on the bottom side), 149 nets.

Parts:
C1, C5, C9, C108, C314, C711, C712, C713: 10nF; C_0402_1005Metric
C2, C6, C10: 1uF; C_1206_3216Metric
C3, C7, C11: 4.7uF; C_1210_3225Metric
C4, C8, C12: 220nF; C_0603_1608Metric
C107: RC DAMP C - TUNE; C_2220_5750Metric
C201: 2.2uF 100V X7R; C_1210_3225Metric
C202: 220nF 100V X7R; C_0805_2012Metric
C203, C209, C211, C301, C303, C305, C307, C310, C601, C603, C605, C701, C702, C801, C902, C904: 100nF; C_0402_1005Metric
C204, C304, C306, C602, C802: 1uF; C_0603_1608Metric
C205, C206, C214, C215: 22uF 25V X7R; C_1210_3225Metric
C208: 1uF 10V; C_0603_1608Metric
C210: 22uF 10V X7R; C_1210_3225Metric
C212, C213: 2.2uF 10V X7R; C_0603_1608Metric
C218, C219: 22uF 16V X7R; C_1210_3225Metric
C302: 10uF 10V; C_0805_2012Metric
C308, C309: 10pF C0G; C_0402_1005Metric
C311: 220nF 100V; C_0805_2012Metric
C312: 10uF 25V X7R; C_1210_3225Metric
C313: 100nF 25V; C_0402_1005Metric
C413, C423, C433: TUNE DNP; C_1206_3216Metric
C501: 1uF 25V; C_0603_1608Metric
C502, C503, C604: 100nF 50V; C_0402_1005Metric
C504: 1nF C0G; C_0603_1608Metric
C505: 100nF 16V; C_0402_1005Metric
C606: 4.7uF 16V X7R; C_0603_1608Metric
C607: 100nF 16V X7R; C_0402_1005Metric
C901, C903: 4.7uF 10V; C_0603_1608Metric
D101: VM TVS - SELECT AFTER TEST; D_SMC
D201, D301: LTST-C19HE1WT; LED_LiteOn_LTST-C19HE1WT
D501: BZT52C12 12V; D_SOD-123
D502, D503: BAT54H; D_SOD-123F
D505: BAT54S; SOT-23
D601: TPD3E001DRYR; TPD3E001_DRY6
D801: PESD2CANFD24V-T; SOT-23
H1, H2, H3, H4: M2 PTH; MountingHole_2.2mm_M2_Pad_Via
J1: MR60PW-M; AMASS_MR60PW-M_1x03_P5.50mm_Horizontal
J101: AMASS XT60PW-M; AMASS_XT60PW-M_1x02_P7.20mm_Horizontal
J201: USB-C service; USB_C_Receptacle_HRO_TYPE-C-31-M-12
J501: BRAKE RESISTOR; SolderWire-2sqmm_1x02_P7.8mm_D2mm_OD3.9mm
J502: BRAKE NTC; JST_GH_SM02B-GHS-TB_1x02-1MP_P1.25mm_Horizontal
J601: EXT ENCODER / HALL; JST_GH_BM06B-GHS-TBT_1x06-1MP_P1.25mm_Vertical
J801: CAN 1; JST_GH_BM04B-GHS-TBT_1x04-1MP_P1.25mm_Vertical
J802: CAN 2; JST_GH_BM04B-GHS-TBT_1x04-1MP_P1.25mm_Vertical
J1001: TC2030-NL SWD; Tag-Connect_TC2030-IDC-NL_2x03_P1.27mm_Vertical
JP601: SENSOR SUPPLY; SolderJumper-3_P1.3mm_Open_Pad1.0x1.5mm
L201: 47uH / 1.9A; WE_LHMI_7050_74437349470
Q201, Q301, Q801: CSD17483F4; CSD17483F4_YJC0003A
Q501: CSD19531Q5A 100V; CSD19531Q5A_Q5A_DQJ0008A
Q802: CSD87502Q2; CSD87502Q2_DLV0006A
R1, R3, R5: 0.5m 1%; R_Shunt_LR2512D_0m5_3W_Kelvin
R2, R4, R6: 4R7; R_0402_1005Metric
R102: RC DAMP R - TUNE; R_2512_6332Metric
R103: 560k 0.1% 75V; R_0603_1608Metric
R105, R419, R429, R439: 28k 0.1%; R_0402_1005Metric
R106, R312, R711, R712, R713, R901: 1k; R_0402_1005Metric
R201: 100k 1%; R_0402_1005Metric
R202: 11.1k 1%; R_0402_1005Metric
R203, R204: 5.1k; R_0402_1005Metric
R206: 15.0k 1%; R_0402_1005Metric
R207, R209, R211, R213: 5.10k 1%; R_0402_1005Metric
R208: 10.0k 1%; R_0402_1005Metric
R210, R212: 22.0k 1%; R_0402_1005Metric
R214: 80.6k 1%; R_0402_1005Metric
R215, R220, R305, R306, R307, R309, R311, R315, R501, R504, R505, R604, R801, R805, R806: 10k; R_0402_1005Metric
R216: 34.0k 0.1%; R_0402_1005Metric
R217: 6.49k 0.1%; R_0402_1005Metric
R218, R219, R310, R615, R616, R617, R804: 100k; R_0402_1005Metric
R221: 33k; R_0402_1005Metric
R301, R302: 0R; R_0402_1005Metric
R303: 2k2; R_0402_1005Metric
R304: 15k; R_0402_1005Metric
R308, R715: 2.2k; R_0402_1005Metric
R313, R314: 22R; R_0402_1005Metric
R410, R420, R430, R441, R442, R443: 56k 0.1%; R_0402_1005Metric
R415, R425, R435: TUNE DNP; R_1206_3216Metric
R417, R418, R427, R428, R437, R438: 1k 0.1%; R_0402_1005Metric
R502, R611: 33R; R_0402_1005Metric
R503: 4.7R; R_0402_1005Metric
R506: 470k 1% 75V; R_0603_1608Metric
R509: 13.3k 1%; R_0402_1005Metric
R510: 1M 1%; R_0402_1005Metric
R511: 10k 1%; R_0402_1005Metric
R512, R701, R702, R703: 4.7k 1%; R_0402_1005Metric
R605, R606, R607, R902, R903: 100R; R_0402_1005Metric
R608, R609, R610: 4.7k DNP; R_0402_1005Metric
R802: 120R 1%; R_0603_1608Metric
R803: 4.7k; R_0402_1005Metric
R904: 22.1k 1%; R_0402_1005Metric
R905: 47.5k 1%; R_0402_1005Metric
SW301: RESET; SW_Push_1P1T-SH_NO_CK_KMR2xxG
TH701, TH702, TH703: 10k NTC B3380; R_0603_1608Metric
TP101: VM; TestPoint_Pad_D1.5mm
TP102: GND; TestPoint_Pad_D1.5mm
TP104: VM BULK; TestPoint_Pad_D3.0mm
TP105: GND BULK; TestPoint_Pad_D3.0mm
U1, U2, U3: CSD88599Q5DC; DMM0022A
U4: STSPIN32G4; QFN_IN32G4_STM
U201: LMR36510FADDAR; LMR36510_DDA
U202: USBLC6-2SC6; USBLC6_SOT23_6
U203: TPS2121RUXR; TPS2121_RUX
U204: TLV75533PDYDR; TLV75533_DYD_GND
U205: MPM3620AGQV-Z; IC18_MPM3620AGQV-Z_MNP
U501: UCC27517ADBVR; UCC27517A_DBV5
U502: TLV3012BIDBVR; SOT-23-6
U601: AS5047P-ATSM; AS5047P_TSSOP14
U602: TMUX1574PW; TMUX1574_PW16
U603: 74LVC3G17; VSSOP-8_2.3x2mm_P0.5mm
U604: TPS2553DBVR; SOT-23-6
U701: BMI323; BMI323_LGA14
U801: TCAN3413DRBR; TCAN3413_DRB8
U901: CP2102N-A02-GQFN20; SiliconLabs_QFN-20-1EP_3x3mm_P0.5mm_EP1.8x1.8mm_ThermalVias
Y301: 24MHz 7pF; Crystal_SMD_3225-4Pin_3.2x2.5mm

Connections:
3V3: C213.1, C301.1, C302.1, C307.1, C503.1, C601.1, C602.1, C603.1, C605.1, C701.1, C702.1, C801.1, C802.1, C901.1, C902.1, C903.1, C904.1, D505.2 (K), J1001.1 (VCC), JP601.1 (A), R301.1, R303.1, R305.1, R308.1, R309.1, R310.1, R511.1, R604.1, R701.1, R702.1, R703.1, R715.1, R801.1, R805.1, R901.1, U4.1 (REG3V3/VDD), U4.2 (VBAT), U4.64 (REGIN), U204.5 (OUT), U502.6 (VDD), U601.11 (VDD), U601.12 (VDD3V3), U602.16 (VDD), U603.8 (VCC), U701.5 (VDDIO), U701.8 (VDD), U701.12 (CSB), U801.3 (VCC), U801.5 (VIO), U901.6 (VDD), U901.7 (VREGIN)
5V_BAT: C218.1, C219.1, R206.1, R210.1, R216.1, U203.7 (IN1), U205.7 (OUT), U205.8 (OUT), U205.9 (OUT)
5V_SYS: C210.1, C211.1, C212.1, D201.4 (A), D301.4 (A), JP601.3 (B), R215.1, U203.1 (OUT), U203.8 (OUT), U204.1 (IN), U204.3 (EN)
5V_USB: C208.1, J201.A4 (VBUS), J201.A9 (VBUS), J201.B4 (VBUS), J201.B9 (VBUS), R208.1, R212.1, R904.1, U202.5 (VBUS), U203.2 (IN2)
/5 V / 3.3 V power/10V_FB: R201.2, R202.1, U201.5 (FB)
/5 V / 3.3 V power/10V_GOOD: R218.2, R219.1, U201.4 (PG), U205.17 (EN)
/5 V / 3.3 V power/U205_AGND: R217.2, U205.3 (AGND)
/5 V / 3.3 V power/U205_SW: U205.4 (SW), U205.5 (SW), U205.6 (SW)
/Brake chopper/BRAKE_NTC_RAW: J502.1, R511.2, R512.1
/Brake chopper/BRAKE_OV_CMD: D503.2 (A), R510.1, U502.1 (OUT)
/Brake chopper/BRAKE_PWM_DRV: D502.1 (K), D503.1 (K), R505.1, U501.3 (IN+)
/CAN interface/CANH_BUS: D801.2 (CANH_IN), J801.2, J802.2, R802.1, U801.7 (CANH)
/CAN interface/CANL_BUS: D801.1 (CANL_IN), J801.3, J802.3, Q802.3 (D2), U801.6 (CANL)
/CAN interface/CAN_SHIELD: J801.4, J802.4
/Current / temperature/NTC_A_RAW: R701.2, R711.1, TH701.1
/Current / temperature/NTC_B_RAW: R702.2, R712.1, TH702.1
/Current / temperature/NTC_C_RAW: R703.2, R713.1, TH703.1
/Current / temperature/OPN_U1: R418.2, R419.2, U4.16 (-)
/Current / temperature/OPN_V1: R428.2, R429.2, U4.22 (-)
/Current / temperature/OPN_W1: R438.2, R439.2, U4.25 (-)
/Current / temperature/OPP_U1: R410.2, R417.2, R441.1, U4.14 (+)
/Current / temperature/OPP_V1: R420.2, R427.2, R442.1, U4.20 (+)
/Current / temperature/OPP_W1: R430.2, R437.2, R443.1, U4.23 (+)
/External feedback/EXT_SUPPLY_SELECTED: C606.1, JP601.2 (C), U604.1 (IN), U604.3 (EN), U604.5 (ILIM)
/External feedback/EXT_VCC: C607.1, J601.1, R608.1, R609.1, R610.1, U604.6 (OUT)
/External feedback/FB_ESD_RAIL: C604.1, D601.6 (VCC)
/MCU / clock / SWD/NRST: C310.1, J1001.3 (~RESET), R303.2, SW301.1, U4.8 (PG10/NRST)
/MCU / clock / SWD/SWCLK: J1001.4 (SWCLK), U4.50 (PA14/SWCLK)
/MCU / clock / SWD/SWDIO: J1001.2 (SWDIO), U4.49 (PA13/SWDIO)
/Three-phase bridge/LS_SOURCE_U: C413.2, R3.1 (POWER+), U1.12 (PGND), U1.13 (PGND), U1.14 (PGND), U1.15 (PGND), U1.16 (PGND), U1.17 (PGND), U1.18 (PGND), U1.19 (PGND), U1.20 (PGND)
/Three-phase bridge/LS_SOURCE_V: C423.2, R1.1 (POWER+), U2.12 (PGND), U2.13 (PGND), U2.14 (PGND), U2.15 (PGND), U2.16 (PGND), U2.17 (PGND), U2.18 (PGND), U2.19 (PGND), U2.20 (PGND)
/Three-phase bridge/LS_SOURCE_W: C433.2, R5.1 (POWER+), U3.12 (PGND), U3.13 (PGND), U3.14 (PGND), U3.15 (PGND), U3.16 (PGND), U3.17 (PGND), U3.18 (PGND), U3.19 (PGND), U3.20 (PGND)
/USB service/CP2102_RST_N: R901.2, U901.9 (RST)
/USB service/CP2102_VBUS_SENSE: R904.2, R905.1, U901.8 (VBUS)
/USB service/UART_BRIDGE_RX: R903.2, U901.17 (RXD)
/USB service/UART_BRIDGE_TX: R902.1, U901.18 (TXD)
/USB service/USB_CC1: J201.A5 (CC1), R203.1
/USB service/USB_CC2: J201.B5 (CC2), R204.1
/USB service/USB_DM: U202.6 (IO1), U901.5 (D-)
/USB service/USB_DM_CONN: J201.A7 (D-), J201.B7 (D-), U202.1 (IO1)
/USB service/USB_DP: U202.4 (IO2), U901.4 (D+)
/USB service/USB_DP_CONN: J201.A6 (D+), J201.B6 (D+), U202.3 (IO2)
AS5047P_CS_N: R309.2, U4.51 (PA15), U601.1 (CSn)
BOOTSTRAP1: C4.2, U4.41 (BOOTSTRAP1)
BOOTSTRAP2: C8.2, U4.38 (BOOTSTRAP2)
BOOTSTRAP3: C12.2, U4.35 (BOOTSTRAP3)
BRAKE_PWM: R501.1, R502.1, U4.60 (PB9)
CAN_STB: R801.2, U4.28 (PB10), U801.8 (STB)
CAN_TERM_DISABLE: R803.1, U4.5 (PC15)
CAN_TERM_GATE: Q301.1 (G), Q801.3 (D), Q802.2 (G1), Q802.5 (G2), R806.2
EXT_FEEDBACK_SELECT: R306.1, U4.53 (PD2), U602.1 (SEL)
EXT_SENSOR_FAULT_N: R604.2, U4.3 (PC13), U604.4 (~FAULT)
FDCAN1_RX: U4.47 (PA11), U801.4 (RXD)
FDCAN1_TX: R805.2, U4.48 (PA12), U801.1 (TXD)
FEEDBACK_A_H1: U4.57 (PB6), U602.4 (D1)
FEEDBACK_B_H2: U4.58 (PB7), U602.7 (D2)
FEEDBACK_I_H3: R307.1, U4.59 (PB8/BOOT0), U602.9 (D3)
GHS1: R2.2, U4.43 (GHS1)
GHS2: R4.2, U4.40 (GHS2)
GHS3: R6.2, U4.37 (GHS3)
GLS1: U1.22 (GL), U4.29 (GLS1)
GLS2: U2.22 (GL), U4.30 (GLS2)
GLS3: U3.22 (GL), U4.31 (GLS3)
GND: C1.2, C2.2, C3.2, C5.2, C6.2, C7.2, C9.2, C10.2, C11.2, C107.2, C108.2, C201.2, C202.2, C204.2, C205.2, C206.2, C208.2, C209.2, C210.2, C211.2, C212.2, C213.2, C214.2, C215.2, C218.2, C219.2, C301.2, C302.2, C303.2, C304.2, C305.2, C306.2, C307.2, C308.2, C309.2, C310.2, C311.2, C312.2, C313.2, C314.2, C501.2, C502.2, C503.2, C504.2, C505.2, C601.2, C602.2, C603.2, C604.2, C605.2, C606.2, C607.2, C701.2, C702.2, C711.2, C712.2, C713.2, C801.2, C802.2, C901.2, C902.2, C903.2, C904.2, D101.2 (A), D501.2 (A), D505.1 (A), D601.3 (GND), D801.3 (GND), J101.1, J201.A1 (GND), J201.A12 (GND), J201.B1 (GND), J201.B12 (GND), J201.S1 (SHIELD), J502.2, J601.2, J801.1, J802.1, J1001.5 (GND), Q201.2 (S), Q301.2 (S), Q501.1 (S), Q501.2 (S), Q501.3 (S), Q801.2 (S), R1.4 (POWER-), R3.4 (POWER-), R5.4 (POWER-), R105.2, R202.2, R203.2, R204.2, R207.2, R209.2, R211.2, R213.2, R214.2, R219.2, R220.2, R306.2, R307.2, R311.2, R315.2, R441.2, R442.2, R443.2, R501.2, R504.2, R505.2, R509.2, R615.2, R616.2, R617.2, R804.2, R905.2, SW301.2, SW301.SH (B), TH701.2, TH702.2, TH703.2, TP102.1, TP105.1, U4.32 (PGND), U4.65 (VSS/EP), U201.1 (PGND), U201.9 (GND), U202.2 (GND), U203.12 (GND), U204.2 (GND), U205.12 (PGND), U205.13 (PGND), U205.14 (PGND), U501.2 (GND), U501.4 (IN-), U502.2 (GND), U601.5 (TEST), U601.13 (GND), U602.2 (S1A), U602.5 (S2A), U602.8 (GND), U602.11 (S3A), U603.4 (GND), U604.2 (GND), U701.1 (SDO/SA0), U701.6 (GNDIO), U701.7 (GND), U801.2 (GND), U801.9 (EP), U901.3 (GND), U901.12 (GND), U901.21 (EP), Y301.2, Y301.4
HS_RETURN_U: C4.1, U1.2 (SH), U4.42 (OUT1)
HS_RETURN_V: C8.1, U2.2 (SH), U4.39 (OUT2)
HS_RETURN_W: C12.1, U3.2 (SH), U4.36 (OUT3)
I2C2_SCL: R308.2, U4.21 (PC4), U701.13 (SCK/SCL)
I2C2_SDA: R715.2, U4.44 (PA8), U701.14 (SDI/SDA)
IMU_INT1: U4.17 (PA4), U701.4 (INT1)
IMU_INT2: U4.18 (PA5), U701.9 (INT2)
INPUT_MUX_ENABLE_N: R305.2, U4.4 (PC14), U602.15 (EN_N)
NTC_BRAKE: C505.1, D505.3 (COM), R512.2, U4.10 (PC1)
NTC_PHASE_A: C711.1, R711.2, U4.12 (PC3)
NTC_PHASE_B: C712.1, R712.2, U4.11 (PC2)
NTC_PHASE_C: C713.1, R713.2, U4.13 (PA0)
unnamed: C107.1, R102.2
unnamed: C413.1, R415.2
unnamed: C423.1, R425.2
unnamed: C433.1, R435.2
unnamed: D201.3 (BK), R220.1
unnamed: D201.2 (GK), R221.1
unnamed: D301.3 (BK), R315.1
unnamed: D301.1 (RK), R304.2
unnamed: D501.1 (K), Q501.4 (G), R503.2, R504.1
unnamed: D502.2 (A), R502.2
unnamed: D601.1 (IO1), J601.5, R607.1
unnamed: D601.2 (IO2), J601.4, R606.1
unnamed: D601.4 (IO3), J601.3, R605.1
unnamed: J501.2, Q501.5 (D), Q501.6 (D), Q501.7 (D), Q501.8 (D)
unnamed: Q201.3 (D), R221.2
unnamed: Q301.3 (D), R304.1
unnamed: Q801.1 (G), R803.2, R804.1
unnamed: Q802.6 (D1), R802.2
unnamed: Q802.1 (S1), Q802.4 (S2)
unnamed: R103.2, R105.1, R106.1
unnamed: R310.2, R311.1, R312.1
unnamed: R605.2, R608.2, R615.1, U603.1
unnamed: R606.2, R609.2, R616.1, U603.3
unnamed: R607.2, R610.2, R617.1, U603.6
unnamed: R2.1, U1.1 (GH)
unnamed: R4.1, U2.1 (GH)
unnamed: R6.1, U3.1 (GH)
unnamed: C308.1, U4.6 (PF0), Y301.1
unnamed: C309.1, U4.7 (PF1), Y301.3
unnamed: C314.1, R312.2, U4.52 (SCREF)
unnamed: C203.1, U201.7 (BOOT)
unnamed: C203.2, L201.1, U201.8 (SW)
unnamed: C204.1, U201.6 (VCC)
unnamed: R208.2, R209.1, U203.3 (CP2)
unnamed: R214.1, U203.10 (ILM)
unnamed: R210.2, R211.1, U203.5 (OV1)
unnamed: R212.2, R213.1, U203.4 (OV2)
unnamed: R206.2, R207.1, U203.6 (PR1)
unnamed: C209.1, U203.11 (SS)
unnamed: R216.2, R217.1, U205.1 (FB)
unnamed: R503.1, U501.5 (OUT)
unnamed: C504.1, R506.2, R509.1, R510.2, U502.3 (IN+)
unnamed: U502.4 (IN-), U502.5 (REF)
unnamed: R313.2, U601.2 (CLK)
unnamed: R611.1, U601.3 (MISO)
unnamed: R314.2, U601.4 (MOSI)
unnamed: U602.3 (S1B), U603.7
unnamed: U602.6 (S2B), U603.5
unnamed: U602.10 (S3B), U603.2
OPO_U1: R419.1, U4.15 (OUT)
OPO_V1: R429.1, U4.19 (OUT)
OPO_W1: R439.1, U4.24 (OUT)
PHASE_U: J1.1 (U), R415.1, U1.3 (VSW), U1.4 (VSW), U1.5 (VSW), U1.6 (VSW), U1.7 (VSW), U1.8 (VSW), U1.9 (VSW), U1.10 (VSW), U1.11 (VSW)
PHASE_V: J1.2 (V), R425.1, U2.3 (VSW), U2.4 (VSW), U2.5 (VSW), U2.6 (VSW), U2.7 (VSW), U2.8 (VSW), U2.9 (VSW), U2.10 (VSW), U2.11 (VSW)
PHASE_W: J1.3 (W), R435.1, U3.3 (VSW), U3.4 (VSW), U3.5 (VSW), U3.6 (VSW), U3.7 (VSW), U3.8 (VSW), U3.9 (VSW), U3.10 (VSW), U3.11 (VSW)
PWR_SOURCE_STATUS: Q201.1 (G), R215.2, U203.9 (ST)
SHUNT_U_SENSE_N: R3.3 (SENSE-), R418.1
SHUNT_U_SENSE_P: R3.2 (SENSE+), R417.1
SHUNT_V_SENSE_N: R1.3 (SENSE-), R428.1
SHUNT_V_SENSE_P: R1.2 (SENSE+), R427.1
SHUNT_W_SENSE_N: R5.3 (SENSE-), R438.1
SHUNT_W_SENSE_P: R5.2 (SENSE+), R437.1
SPI3_MISO: R611.2, U4.55 (PB4)
SPI3_MOSI_MCU: R314.1, U4.56 (PB5)
SPI3_SCK_MCU: R313.1, U4.54 (PB3)
USB_UART_RX: R902.2, U4.46 (PA10)
USB_UART_TX: R903.1, U4.45 (PA9)
VBUS_MUX_IN: R106.2, U602.13 (S4A), U602.14 (S4B)
VBUS_SENSE: C108.1, U4.9 (PC0), U602.12 (D4)
VCC: C205.1, C206.1, C214.1, C215.1, C312.1, C313.1, C501.1, C502.1, L201.2, R201.1, R218.1, R806.1, U4.63 (VCC), U205.16 (IN), U501.1 (VDD)
VDDA: C303.1, C304.1, R301.2, R302.1, U4.27 (VDDA)
VM: C1.1, C2.1, C3.1, C5.1, C6.1, C7.1, C9.1, C10.1, C11.1, C201.1, C202.1, C311.1, D101.1 (K), J101.2, J501.1, R102.1, R103.1, R506.1, TP101.1, TP104.1, U1.27 (VIN), U2.27 (VIN), U3.27 (VIN), U4.61 (VM), U4.62 (SW), U201.2 (VIN), U201.3 (EN)
VREF+: C305.1, C306.1, R302.2, R410.1, R420.1, R430.1, U4.26 (VREF+)

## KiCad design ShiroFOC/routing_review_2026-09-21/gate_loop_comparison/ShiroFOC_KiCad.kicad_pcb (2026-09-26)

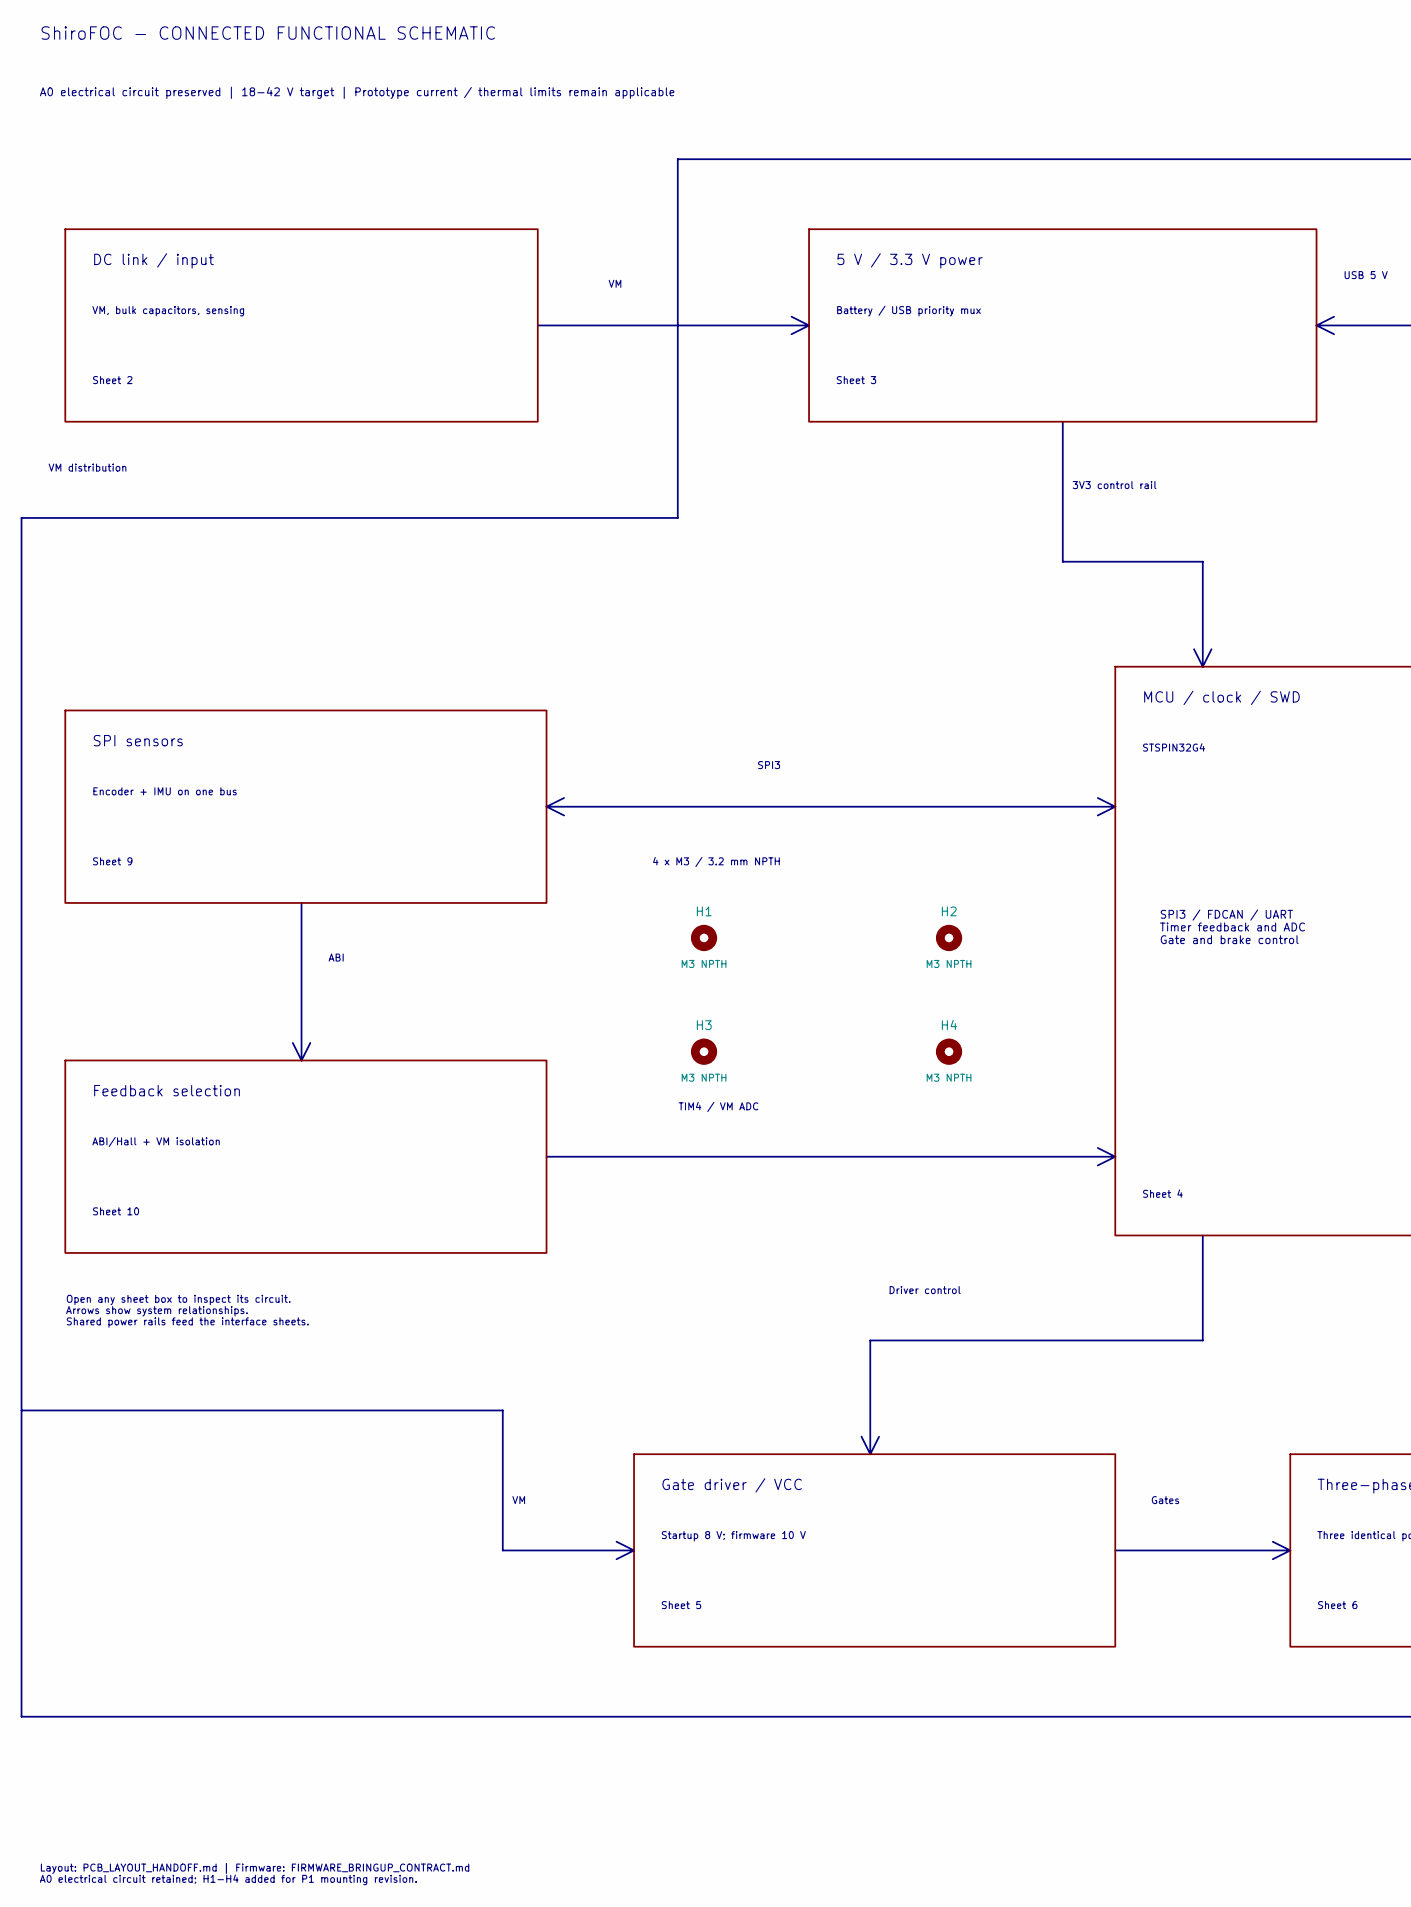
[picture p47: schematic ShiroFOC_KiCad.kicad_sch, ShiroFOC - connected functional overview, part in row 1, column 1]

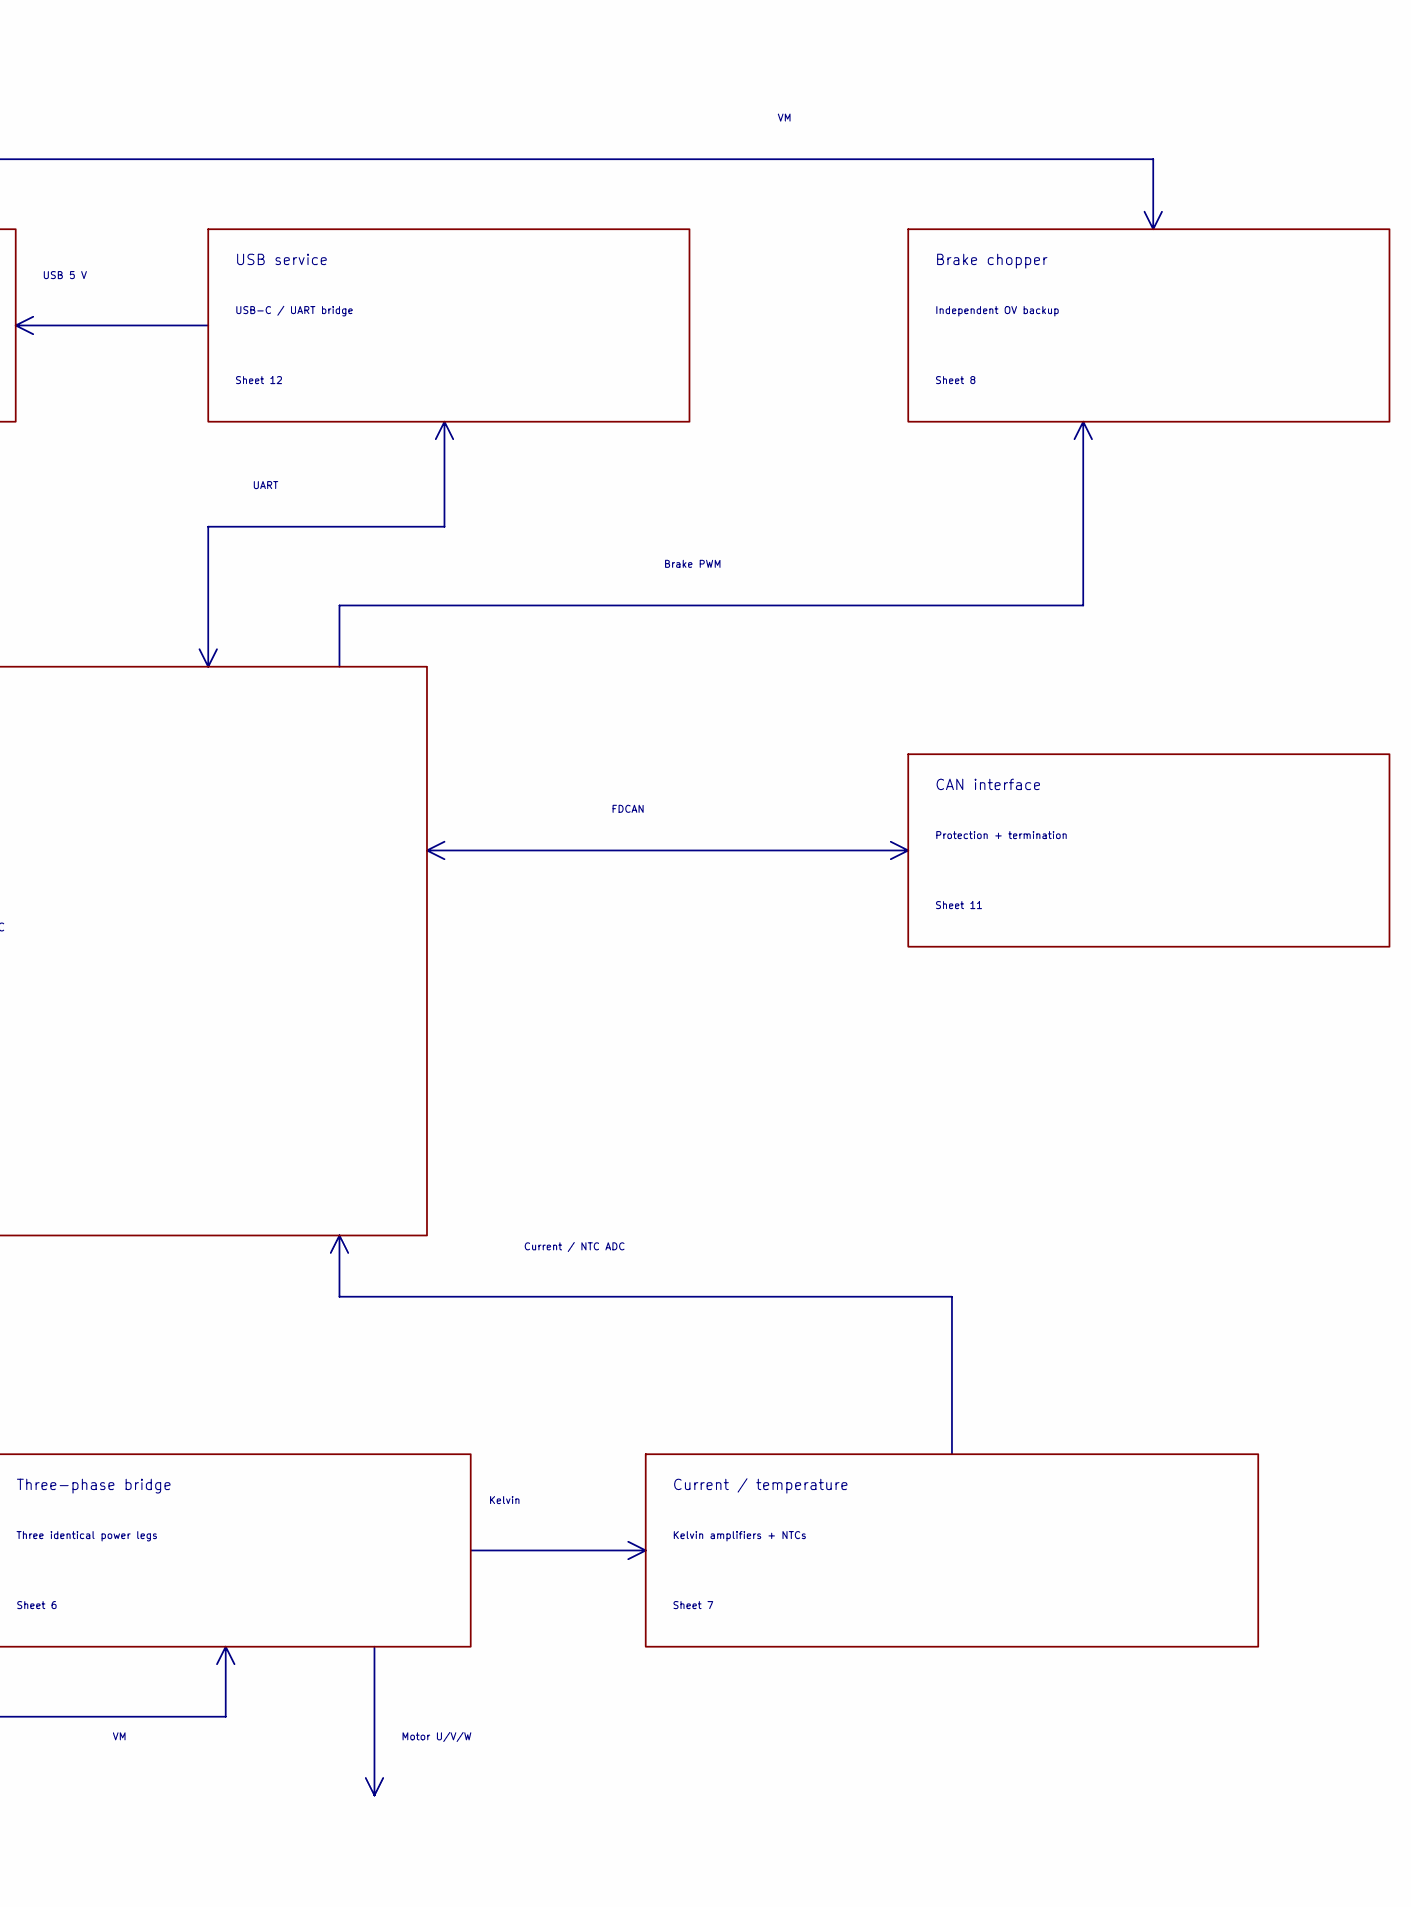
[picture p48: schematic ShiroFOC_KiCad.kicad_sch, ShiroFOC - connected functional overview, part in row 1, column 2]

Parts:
H1, H2, H3, H4: M3 NPTH; MountingHole_3.2mm_M3

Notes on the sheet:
ShiroFOC - CONNECTED FUNCTIONAL SCHEMATIC
A0 electrical circuit preserved | 18-42 V target | Prototype current / thermal limits remain applicable
DC link / input
VM, bulk capacitors, sensing
Sheet 2
5 V / 3.3 V power
Battery / USB priority mux
Sheet 3
MCU / clock / SWD
STSPIN32G4
Sheet 4
Gate driver / VCC
Startup 8 V; firmware 10 V
Sheet 5
Three-phase bridge
Three identical power legs
Sheet 6
Current / temperature
Kelvin amplifiers + NTCs
Sheet 7
Brake chopper
Independent OV backup
Sheet 8
SPI sensors
Encoder + IMU on one bus
Sheet 9
Feedback selection
ABI/Hall + VM isolation
Sheet 10
CAN interface
Protection + termination
Sheet 11
USB service
USB-C / UART bridge
Sheet 12
SPI3 / FDCAN / UART Timer feedback and ADC Gate and brake control
USB 5 V
3V3 control rail
UART
Brake PWM

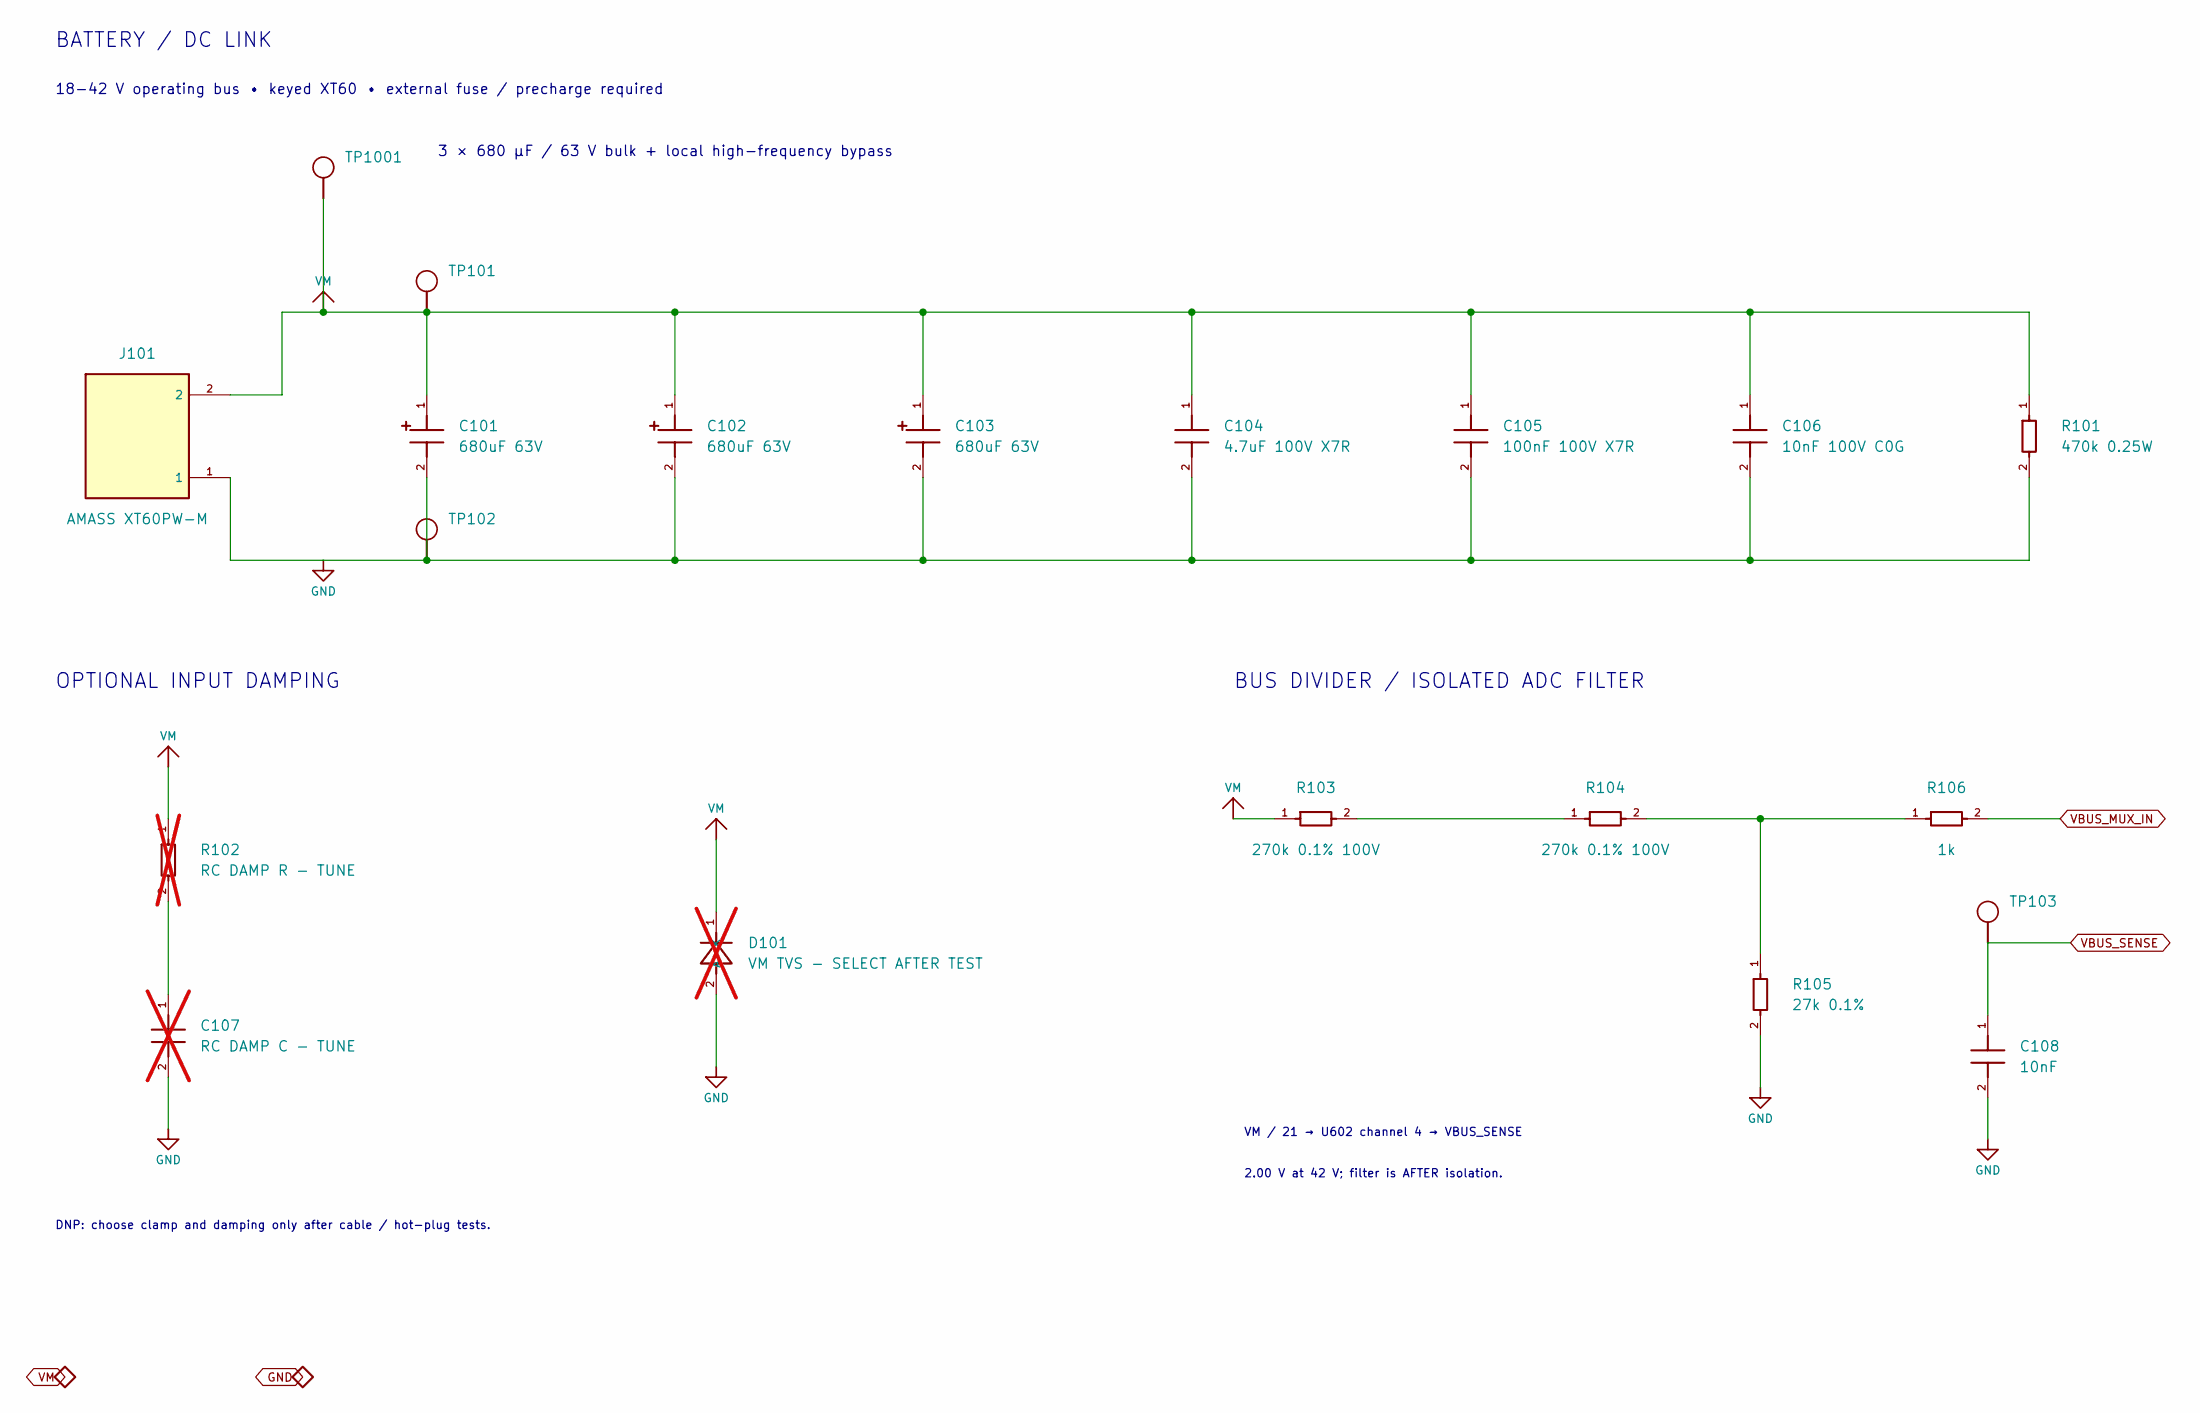
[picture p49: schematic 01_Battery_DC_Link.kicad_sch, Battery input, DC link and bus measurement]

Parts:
C101, C102, C103: 680uF 63V; CP_Elec_18x17.5; Rating See Value; generic low-voltage passives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; MPN EEVFK1J681M
C104: 4.7uF 100V X7R; C_1210_3225Metric; Rating See Value; generic low-voltage passives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
C105: 100nF 100V X7R; C_0805_2012Metric; Rating See Value; generic low-voltage passives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
C106: 10nF 100V C0G; C_0603_1608Metric; Rating See Value; generic low-voltage passives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
C107: RC DAMP C - TUNE; C_2220_5750Metric; Rating See Value; generic low-voltage passives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; not fitted
C108: 10nF; C_0603_1608Metric; Rating See Value; generic low-voltage passives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
D101: VM TVS - SELECT AFTER TEST; D_SMC; Rating See Value; generic low-voltage passives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; not fitted
J101: AMASS XT60PW-M; AMASS_XT60PW-M_1x02_P7.20mm_Horizontal; Rating See Value; generic low-voltage passives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; MPN XT60PW-M
R101: 470k 0.25W; R_1206_3216Metric; Rating See Value; generic low-voltage passives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
R102: RC DAMP R - TUNE; R_2512_6332Metric; Rating See Value; generic low-voltage passives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; not fitted
R103, R104: 270k 0.1% 100V; R_1206_3216Metric; Rating See Value; generic low-voltage passives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
R105: 27k 0.1%; R_0603_1608Metric; Rating See Value; generic low-voltage passives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
R106: 1k; R_0603_1608Metric; Rating See Value; generic low-voltage passives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
TP101: VM; TestPoint_Pad_D1.5mm; Rating See Value; generic low-voltage passives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; MPN PCB feature
TP102: GND; TestPoint_Pad_D1.5mm; Rating See Value; generic low-voltage passives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; MPN PCB feature
TP103: VBUS_SENSE; TestPoint_Pad_D1.5mm; Rating See Value; generic low-voltage passives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; MPN PCB feature
TP1001: VM; TestPoint_Pad_D1.0mm; Rating See Value; generic low-voltage passives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; MPN PCB feature

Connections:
GND: C101.2, C102.2, C103.2, C104.2, C105.2, C106.2, C107.2, C108.2, D101.2 (A), J101.1, R101.2, R105.2, TP102.1; also elsewhere on the board
unnamed: C107.1, R102.2
unnamed: R103.2, R104.1
unnamed: R104.2, R105.1, R106.1
VBUS_MUX_IN: R106.2; also elsewhere on the board
VBUS_SENSE: C108.1, TP103.1; also elsewhere on the board
VM: C101.1, C102.1, C103.1, C104.1, C105.1, C106.1, D101.1 (K), J101.2, R101.1, R102.1, R103.1, TP101.1, TP1001.1; also elsewhere on the board

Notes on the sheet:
BATTERY / DC LINK
18-42 V operating bus • keyed XT60 • external fuse / precharge required
3 × 680 µF / 63 V bulk + local high-frequency bypass
OPTIONAL INPUT DAMPING
DNP: choose clamp and damping only after cable / hot-plug tests.
BUS DIVIDER / ISOLATED ADC FILTER
VM / 21 → U602 channel 4 → VBUS_SENSE
2.00 V at 42 V; filter is AFTER isolation.

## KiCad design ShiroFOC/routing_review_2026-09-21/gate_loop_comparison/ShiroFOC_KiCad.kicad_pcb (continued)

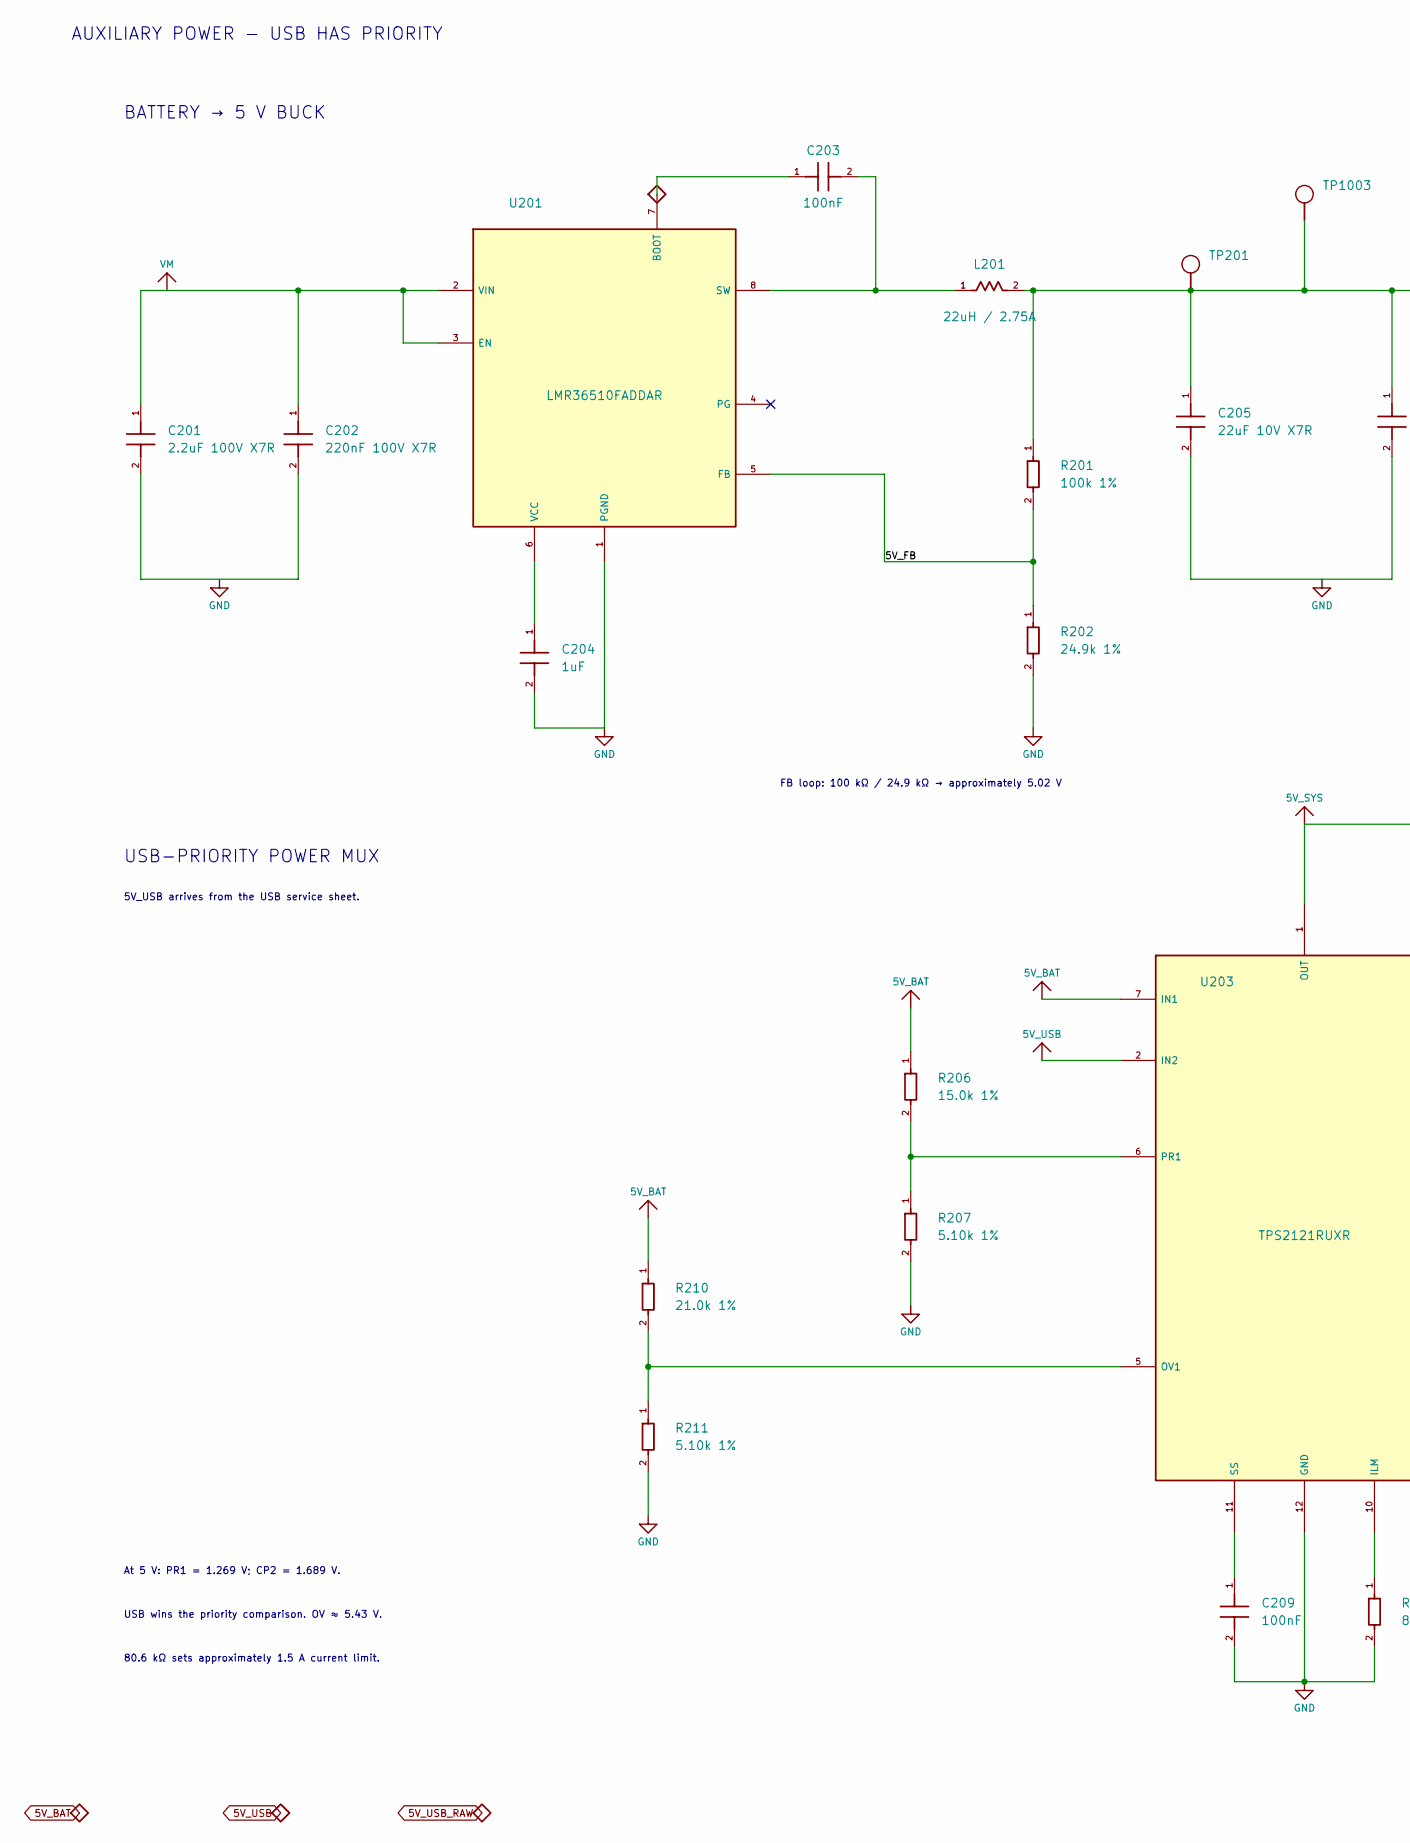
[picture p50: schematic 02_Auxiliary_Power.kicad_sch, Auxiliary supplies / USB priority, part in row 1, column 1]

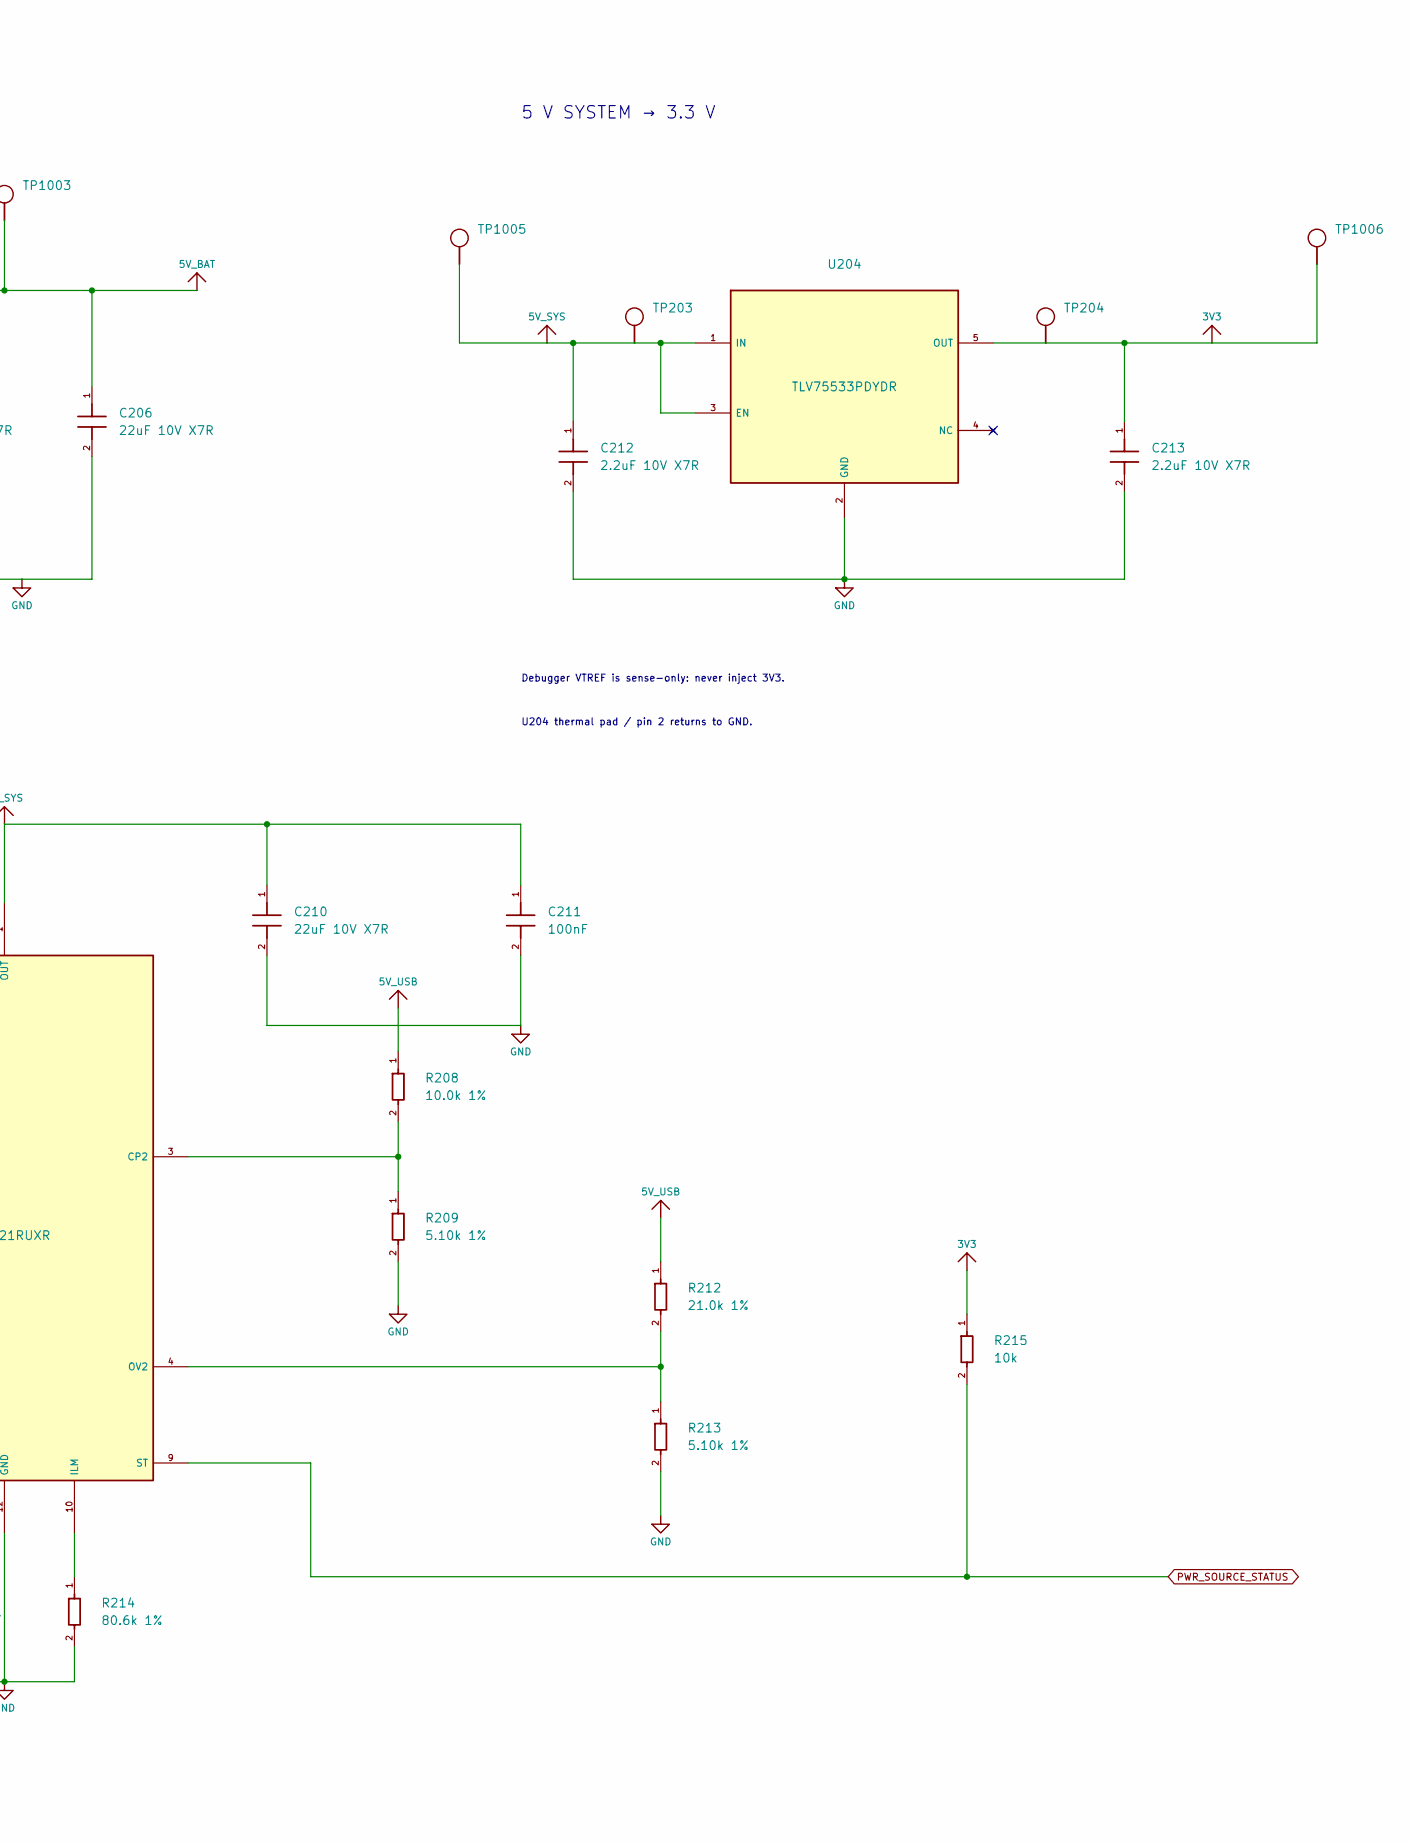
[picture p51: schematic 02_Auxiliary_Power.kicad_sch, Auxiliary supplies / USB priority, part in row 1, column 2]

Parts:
C201: 2.2uF 100V X7R; C_1210_3225Metric; Rating See Value; generic low-voltage passives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
C202: 220nF 100V X7R; C_0805_2012Metric; Rating See Value; generic low-voltage passives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
C203, C209, C211: 100nF; C_0603_1608Metric; Rating See Value; generic low-voltage passives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
C204: 1uF; C_0603_1608Metric; Rating See Value; generic low-voltage passives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
C205, C206, C210: 22uF 10V X7R; C_1210_3225Metric; Rating See Value; generic low-voltage passives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
C212, C213: 2.2uF 10V X7R; C_0603_1608Metric; Rating See Value; generic low-voltage passives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
L201: 22uH / 2.75A; WE_LHMI_7050_74437349220; Rating See Value; generic low-voltage passives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; MPN 74437349220
R201: 100k 1%; R_0603_1608Metric; Rating See Value; generic low-voltage passives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
R202: 24.9k 1%; R_0603_1608Metric; Rating See Value; generic low-voltage passives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
R206: 15.0k 1%; R_0603_1608Metric; Rating See Value; generic low-voltage passives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
R207, R209, R211, R213: 5.10k 1%; R_0603_1608Metric; Rating See Value; generic low-voltage passives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
R208: 10.0k 1%; R_0603_1608Metric; Rating See Value; generic low-voltage passives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
R210, R212: 21.0k 1%; R_0603_1608Metric; Rating See Value; generic low-voltage passives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
R214: 80.6k 1%; R_0603_1608Metric; Rating See Value; generic low-voltage passives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
R215: 10k; R_0603_1608Metric; Rating See Value; generic low-voltage passives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
TP201: 5V_BAT; TestPoint_Pad_D1.5mm; Rating See Value; generic low-voltage passives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; MPN PCB feature
TP203: 5V_SYS; TestPoint_Pad_D1.5mm; Rating See Value; generic low-voltage passives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; MPN PCB feature
TP204: 3V3; TestPoint_Pad_D1.5mm; Rating See Value; generic low-voltage passives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; MPN PCB feature
TP1003: 5V_BAT; TestPoint_Pad_D1.0mm; Rating See Value; generic low-voltage passives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; MPN PCB feature
TP1005: 5V_SYS; TestPoint_Pad_D1.0mm; Rating See Value; generic low-voltage passives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; MPN PCB feature
TP1006: 3V3; TestPoint_Pad_D1.0mm; Rating See Value; generic low-voltage passives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; MPN PCB feature
U201: LMR36510FADDAR; Texas_HTSOP-8-1EP_3.9x4.9mm_P1.27mm_EP2.95x4.9mm_Mask2.4x3.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; Rating See Value; generic low-voltage passives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; MPN LMR36510FADDAR
U203: TPS2121RUXR; Texas_VQFN-HR-12_2x2.5mm_P0.5mm_ThermalVias; Rating See Value; generic low-voltage passives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; MPN TPS2121RUXR
U204: TLV75533PDYDR; Texas_DYD0005A_SOT23-5; Rating See Value; generic low-voltage passives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; MPN TLV75533PDYDR

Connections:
3V3: C213.1, R215.1, TP204.1, TP1006.1, U204.5 (OUT); also elsewhere on the board
5V_BAT: C205.1, C206.1, L201.2, R201.1, R206.1, R210.1, TP201.1, TP1003.1, U203.7 (IN1)
5V_SYS: C210.1, C211.1, C212.1, TP203.1, TP1005.1, U203.1 (OUT), U203.8 (OUT), U204.1 (IN), U204.3 (EN)
5V_USB: R208.1, R212.1, U203.2 (IN2); also elsewhere on the board
/5 V / 3.3 V power/5V_FB: R201.2, R202.1, U201.5 (FB)
GND: C201.2, C202.2, C204.2, C205.2, C206.2, C209.2, C210.2, C211.2, C212.2, C213.2, R202.2, R207.2, R209.2, R211.2, R213.2, R214.2, U201.1 (PGND), U201.9 (GND), U203.12 (GND), U204.2 (GND); also elsewhere on the board
unnamed: C203.1, U201.7 (BOOT)
unnamed: C203.2, L201.1, U201.8 (SW)
unnamed: C204.1, U201.6 (VCC)
unnamed: R208.2, R209.1, U203.3 (CP2)
unnamed: R214.1, U203.10 (ILM)
unnamed: R210.2, R211.1, U203.5 (OV1)
unnamed: R212.2, R213.1, U203.4 (OV2)
unnamed: R206.2, R207.1, U203.6 (PR1)
unnamed: C209.1, U203.11 (SS)
PWR_SOURCE_STATUS: R215.2, U203.9 (ST)
VM: C201.1, C202.1, U201.2 (VIN), U201.3 (EN); also elsewhere on the board

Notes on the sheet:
AUXILIARY POWER - USB HAS PRIORITY
BATTERY → 5 V BUCK
FB loop: 100 kΩ / 24.9 kΩ → approximately 5.02 V
5 V SYSTEM → 3.3 V
Debugger VTREF is sense-only: never inject 3V3.
U204 thermal pad / pin 2 returns to GND.
USB-PRIORITY POWER MUX
5V_USB arrives from the USB service sheet.
At 5 V: PR1 = 1.269 V; CP2 = 1.689 V.
USB wins the priority comparison. OV ≈ 5.43 V.
80.6 kΩ sets approximately 1.5 A current limit.

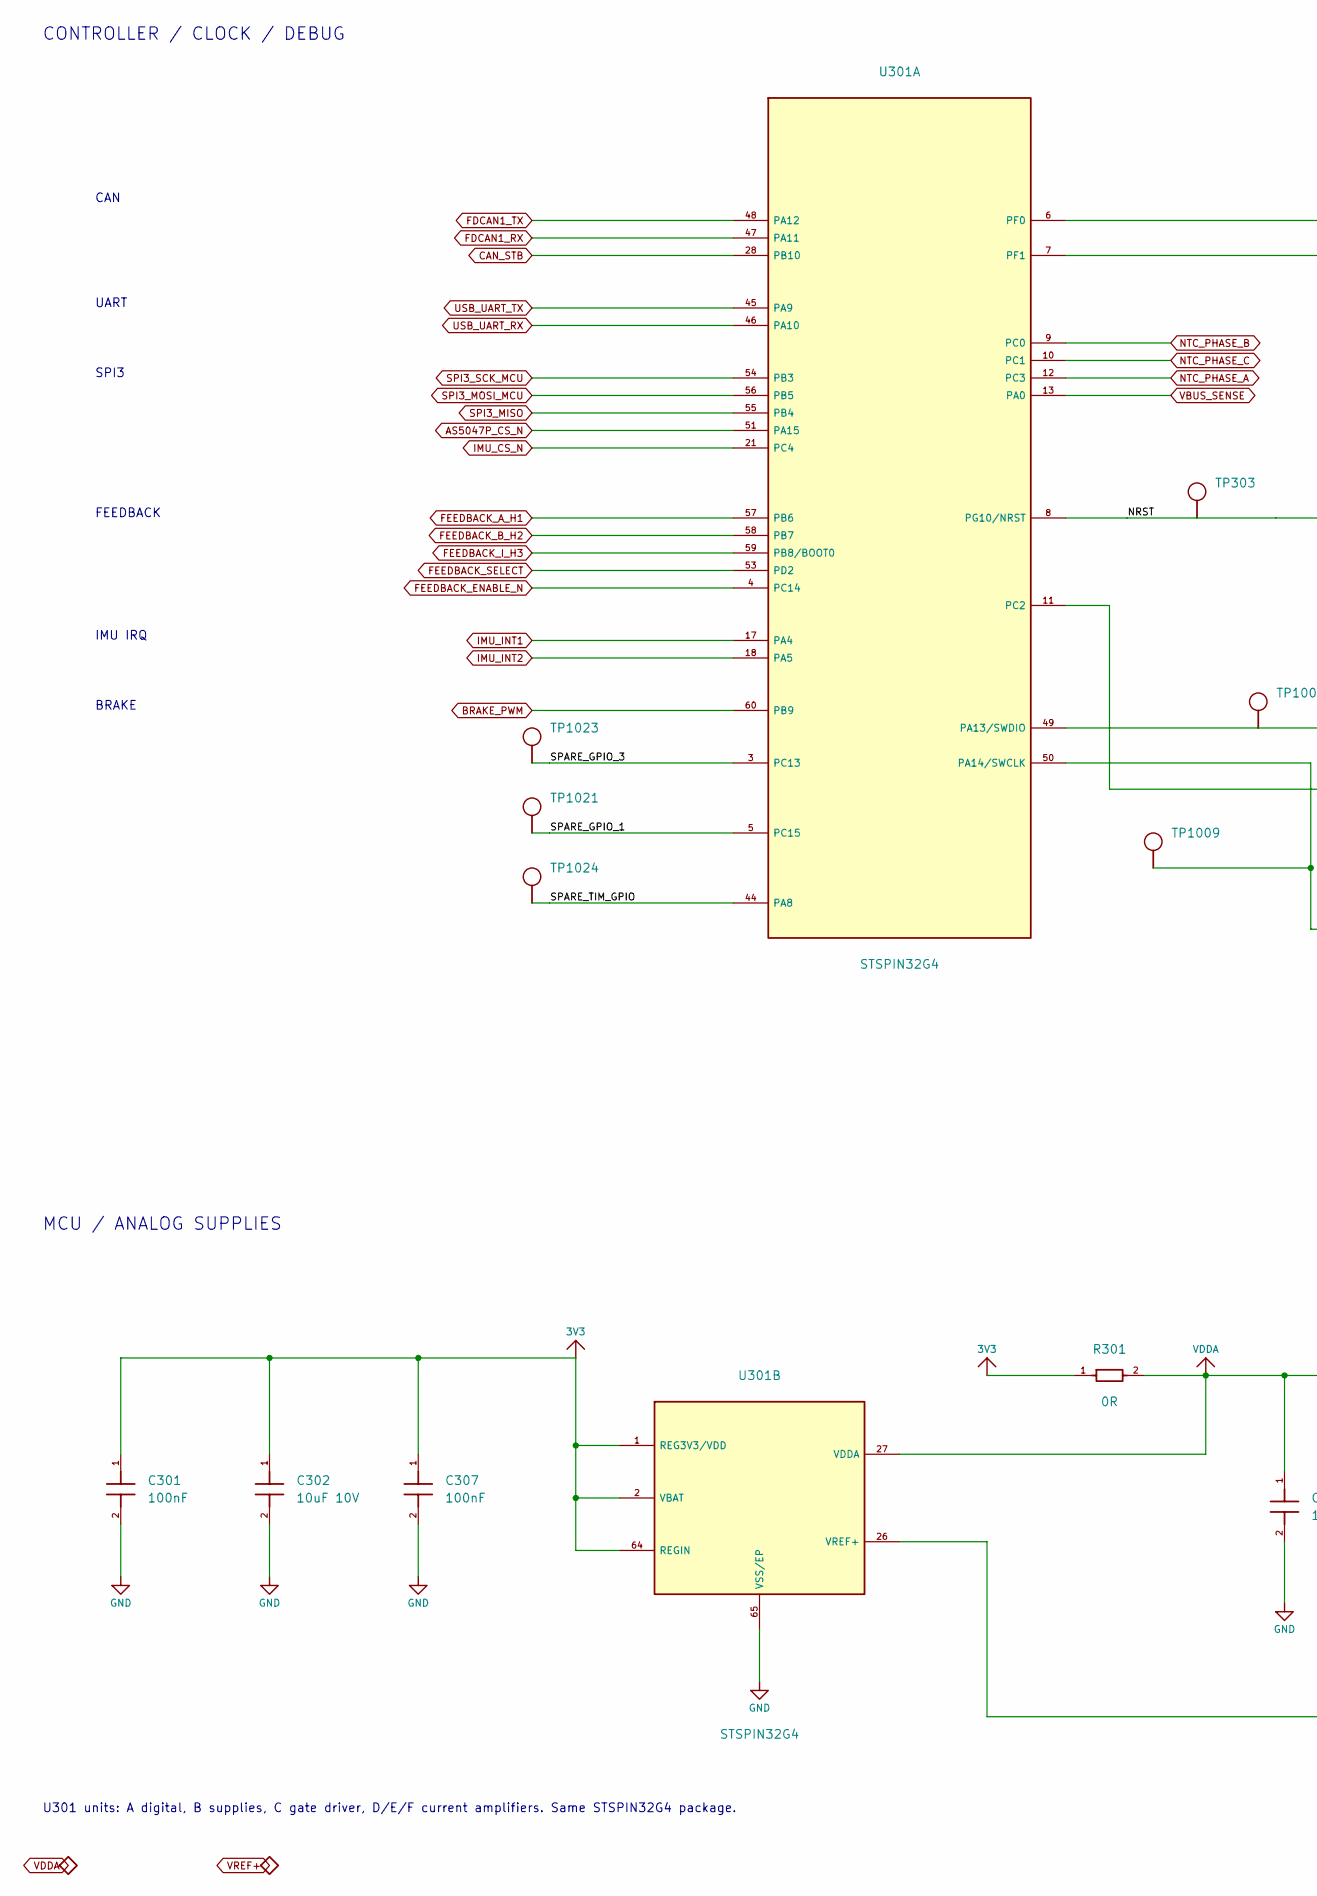
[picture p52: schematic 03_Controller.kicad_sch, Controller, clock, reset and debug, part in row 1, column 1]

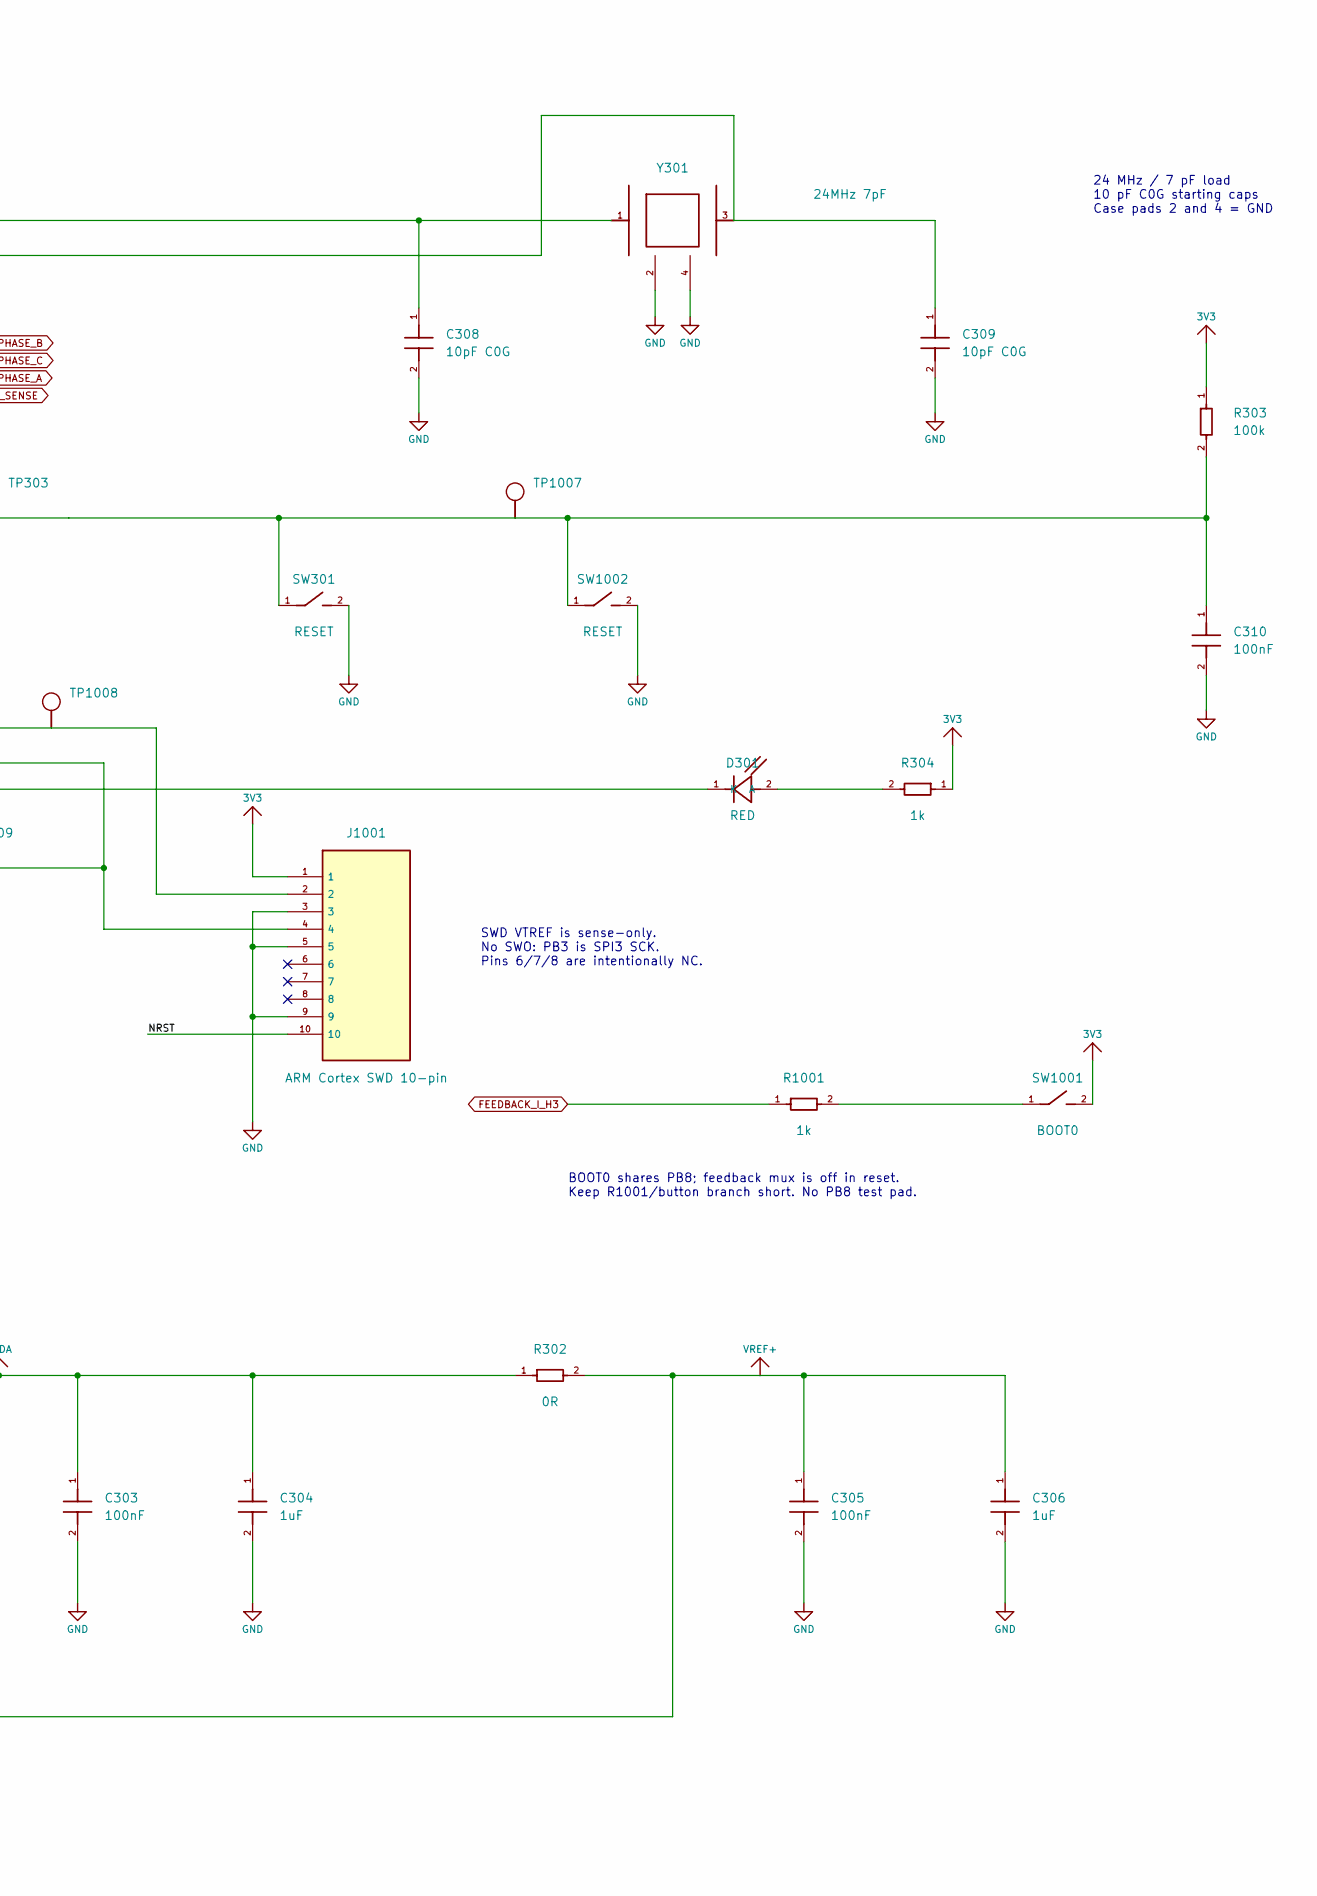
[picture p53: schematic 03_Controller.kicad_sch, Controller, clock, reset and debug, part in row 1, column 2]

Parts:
C301, C303, C305, C307, C310: 100nF; C_0603_1608Metric; Rating See Value; generic low-voltage passives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
C302: 10uF 10V; C_0805_2012Metric; Rating See Value; generic low-voltage passives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
C304, C306: 1uF; C_0603_1608Metric; Rating See Value; generic low-voltage passives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
C308, C309: 10pF C0G; C_0603_1608Metric; Rating See Value; generic low-voltage passives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
D301: RED; LED_0603_1608Metric; Rating See Value; generic low-voltage passives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
J1001: ARM Cortex SWD 10-pin; PinHeader_2x05_P1.27mm_Vertical_SMD; Rating See Value; generic low-voltage passives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; MPN FTSH-105-01-L-DV-K
R301, R302: 0R; R_0603_1608Metric; Rating See Value; generic low-voltage passives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
R303: 100k; R_0603_1608Metric; Rating See Value; generic low-voltage passives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
R304, R1001: 1k; R_0603_1608Metric; Rating See Value; generic low-voltage passives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
SW301, SW1002: RESET; SW_SPST_TL3305A; Rating See Value; generic low-voltage passives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
SW1001: BOOT0; SW_SPST_TL3305A; Rating See Value; generic low-voltage passives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
TP303: NRST; TestPoint_Pad_D1.5mm; Rating See Value; generic low-voltage passives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; MPN PCB feature
TP1007: NRST; TestPoint_Pad_D1.0mm; Rating See Value; generic low-voltage passives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; MPN PCB feature
TP1008: SWDIO; TestPoint_Pad_D1.0mm; Rating See Value; generic low-voltage passives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; MPN PCB feature
TP1009: SWCLK; TestPoint_Pad_D1.0mm; Rating See Value; generic low-voltage passives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; MPN PCB feature
TP1021: SPARE_GPIO_1; TestPoint_Pad_D1.0mm; Rating See Value; generic low-voltage passives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; MPN PCB feature
TP1023: SPARE_GPIO_3; TestPoint_Pad_D1.0mm; Rating See Value; generic low-voltage passives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; MPN PCB feature
TP1024: SPARE_TIM_GPIO; TestPoint_Pad_D1.0mm; Rating See Value; generic low-voltage passives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; MPN PCB feature
U301: STSPIN32G4; QFN-64-1EP_9x9mm_P0.5mm_EP4.1x4.1mm_ThermalVias; Rating See Value; generic low-voltage passives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; MPN STSPIN32G4
Y301: 24MHz 7pF; Crystal_SMD_3225-4Pin_3.2x2.5mm; Rating See Value; generic low-voltage passives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; MPN 0132M4-24.000F07DTNLL

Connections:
3V3: C301.1, C302.1, C307.1, J1001.1, R301.1, R303.1, R304.1, SW1001.2, U301.1 (REG3V3/VDD), U301.2 (VBAT), U301.64 (REGIN); also elsewhere on the board
/MCU / clock / SWD/NRST: C310.1, J1001.10, R303.2, SW301.1, SW1002.1, TP303.1, TP1007.1, U301.8 (PG10/NRST)
/MCU / clock / SWD/SPARE_GPIO_1: TP1021.1, U301.5 (PC15)
/MCU / clock / SWD/SPARE_GPIO_3: TP1023.1, U301.3 (PC13)
/MCU / clock / SWD/SPARE_TIM_GPIO: TP1024.1, U301.44 (PA8)
AS5047P_CS_N: U301.51 (PA15); also elsewhere on the board
BRAKE_PWM: U301.60 (PB9); also elsewhere on the board
CAN_STB: U301.28 (PB10); also elsewhere on the board
FDCAN1_RX: U301.47 (PA11); also elsewhere on the board
FDCAN1_TX: U301.48 (PA12); also elsewhere on the board
FEEDBACK_A_H1: U301.57 (PB6); also elsewhere on the board
FEEDBACK_B_H2: U301.58 (PB7); also elsewhere on the board
FEEDBACK_ENABLE_N: U301.4 (PC14); also elsewhere on the board
FEEDBACK_I_H3: R1001.1, U301.59 (PB8/BOOT0); also elsewhere on the board
FEEDBACK_SELECT: U301.53 (PD2); also elsewhere on the board
GND: C301.2, C302.2, C303.2, C304.2, C305.2, C306.2, C307.2, C308.2, C309.2, C310.2, J1001.3, J1001.5, J1001.9, SW301.2, SW1002.2, U301.65 (VSS/EP), Y301.2, Y301.4; also elsewhere on the board
IMU_CS_N: U301.21 (PC4); also elsewhere on the board
IMU_INT1: U301.17 (PA4); also elsewhere on the board
IMU_INT2: U301.18 (PA5); also elsewhere on the board
NTC_PHASE_A: U301.12 (PC3); also elsewhere on the board
NTC_PHASE_B: U301.9 (PC0); also elsewhere on the board
NTC_PHASE_C: U301.10 (PC1); also elsewhere on the board
unnamed: D301.2 (A), R304.2
unnamed: D301.1 (K), U301.11 (PC2)
unnamed: R1001.2, SW1001.1
unnamed: J1001.2, TP1008.1, U301.49 (PA13/SWDIO)
unnamed: J1001.4, TP1009.1, U301.50 (PA14/SWCLK)
unnamed: C308.1, U301.6 (PF0), Y301.1
unnamed: C309.1, U301.7 (PF1), Y301.3
SPI3_MISO: U301.55 (PB4); also elsewhere on the board
SPI3_MOSI_MCU: U301.56 (PB5); also elsewhere on the board
SPI3_SCK_MCU: U301.54 (PB3); also elsewhere on the board
USB_UART_RX: U301.46 (PA10); also elsewhere on the board
USB_UART_TX: U301.45 (PA9); also elsewhere on the board
VBUS_SENSE: U301.13 (PA0); also elsewhere on the board
VDDA: C303.1, C304.1, R301.2, R302.1, U301.27 (VDDA)
VREF+: C305.1, C306.1, R302.2, U301.26 (VREF+); also elsewhere on the board

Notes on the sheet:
CONTROLLER / CLOCK / DEBUG
CAN
UART
SPI3
FEEDBACK
IMU IRQ
BRAKE
24 MHz / 7 pF load 10 pF C0G starting caps Case pads 2 and 4 = GND
SWD VTREF is sense-only. No SWO: PB3 is SPI3 SCK. Pins 6/7/8 are intentionally NC.
BOOT0 shares PB8; feedback mux is off in reset. Keep R1001/button branch short. No PB8 test pad.
MCU / ANALOG SUPPLIES
U301 units: A digital, B supplies, C gate driver, D/E/F current amplifiers. Same STSPIN32G4 package.

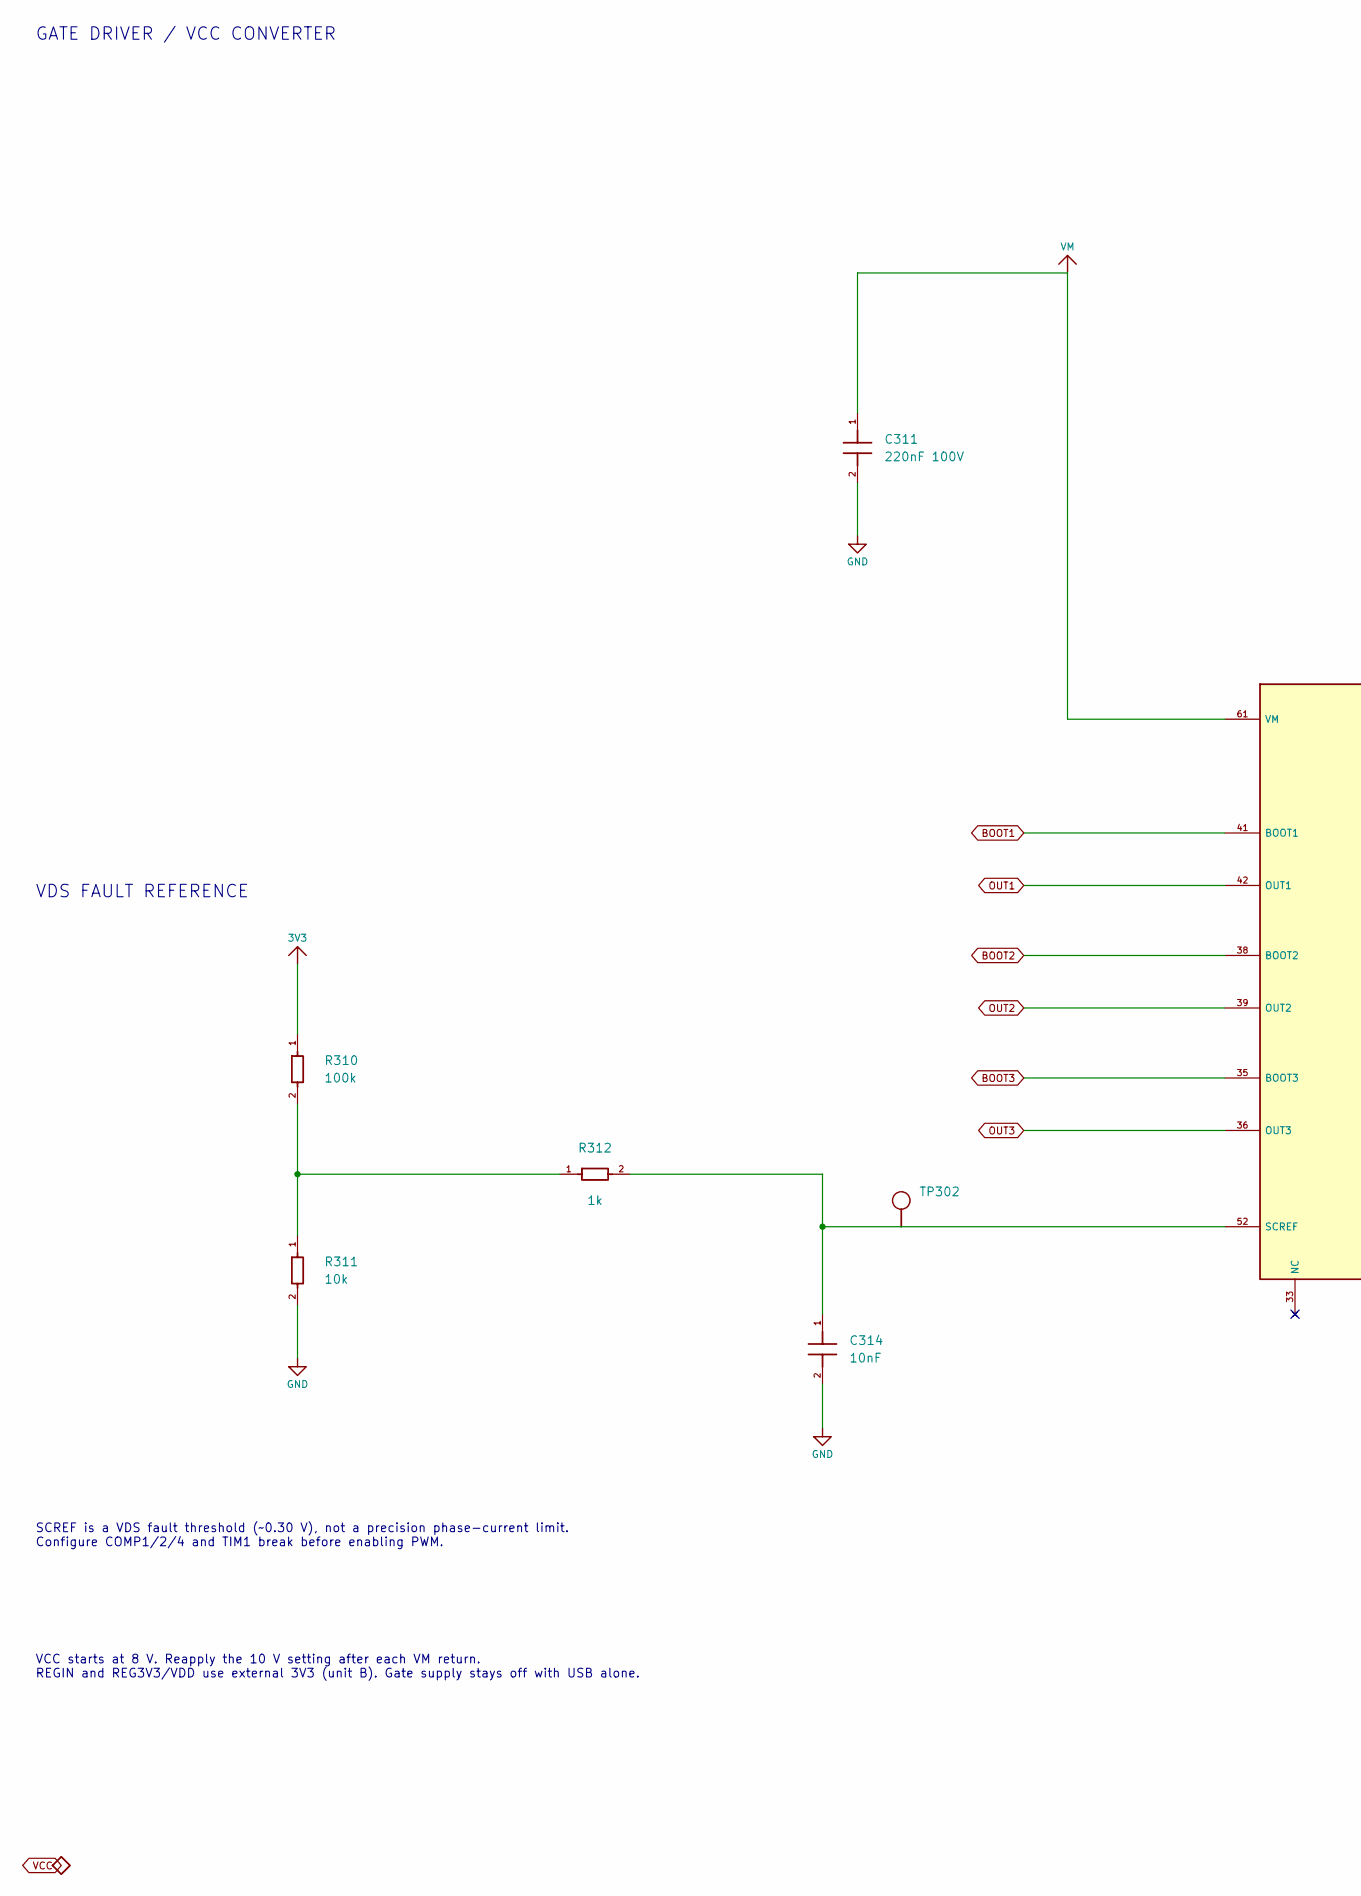
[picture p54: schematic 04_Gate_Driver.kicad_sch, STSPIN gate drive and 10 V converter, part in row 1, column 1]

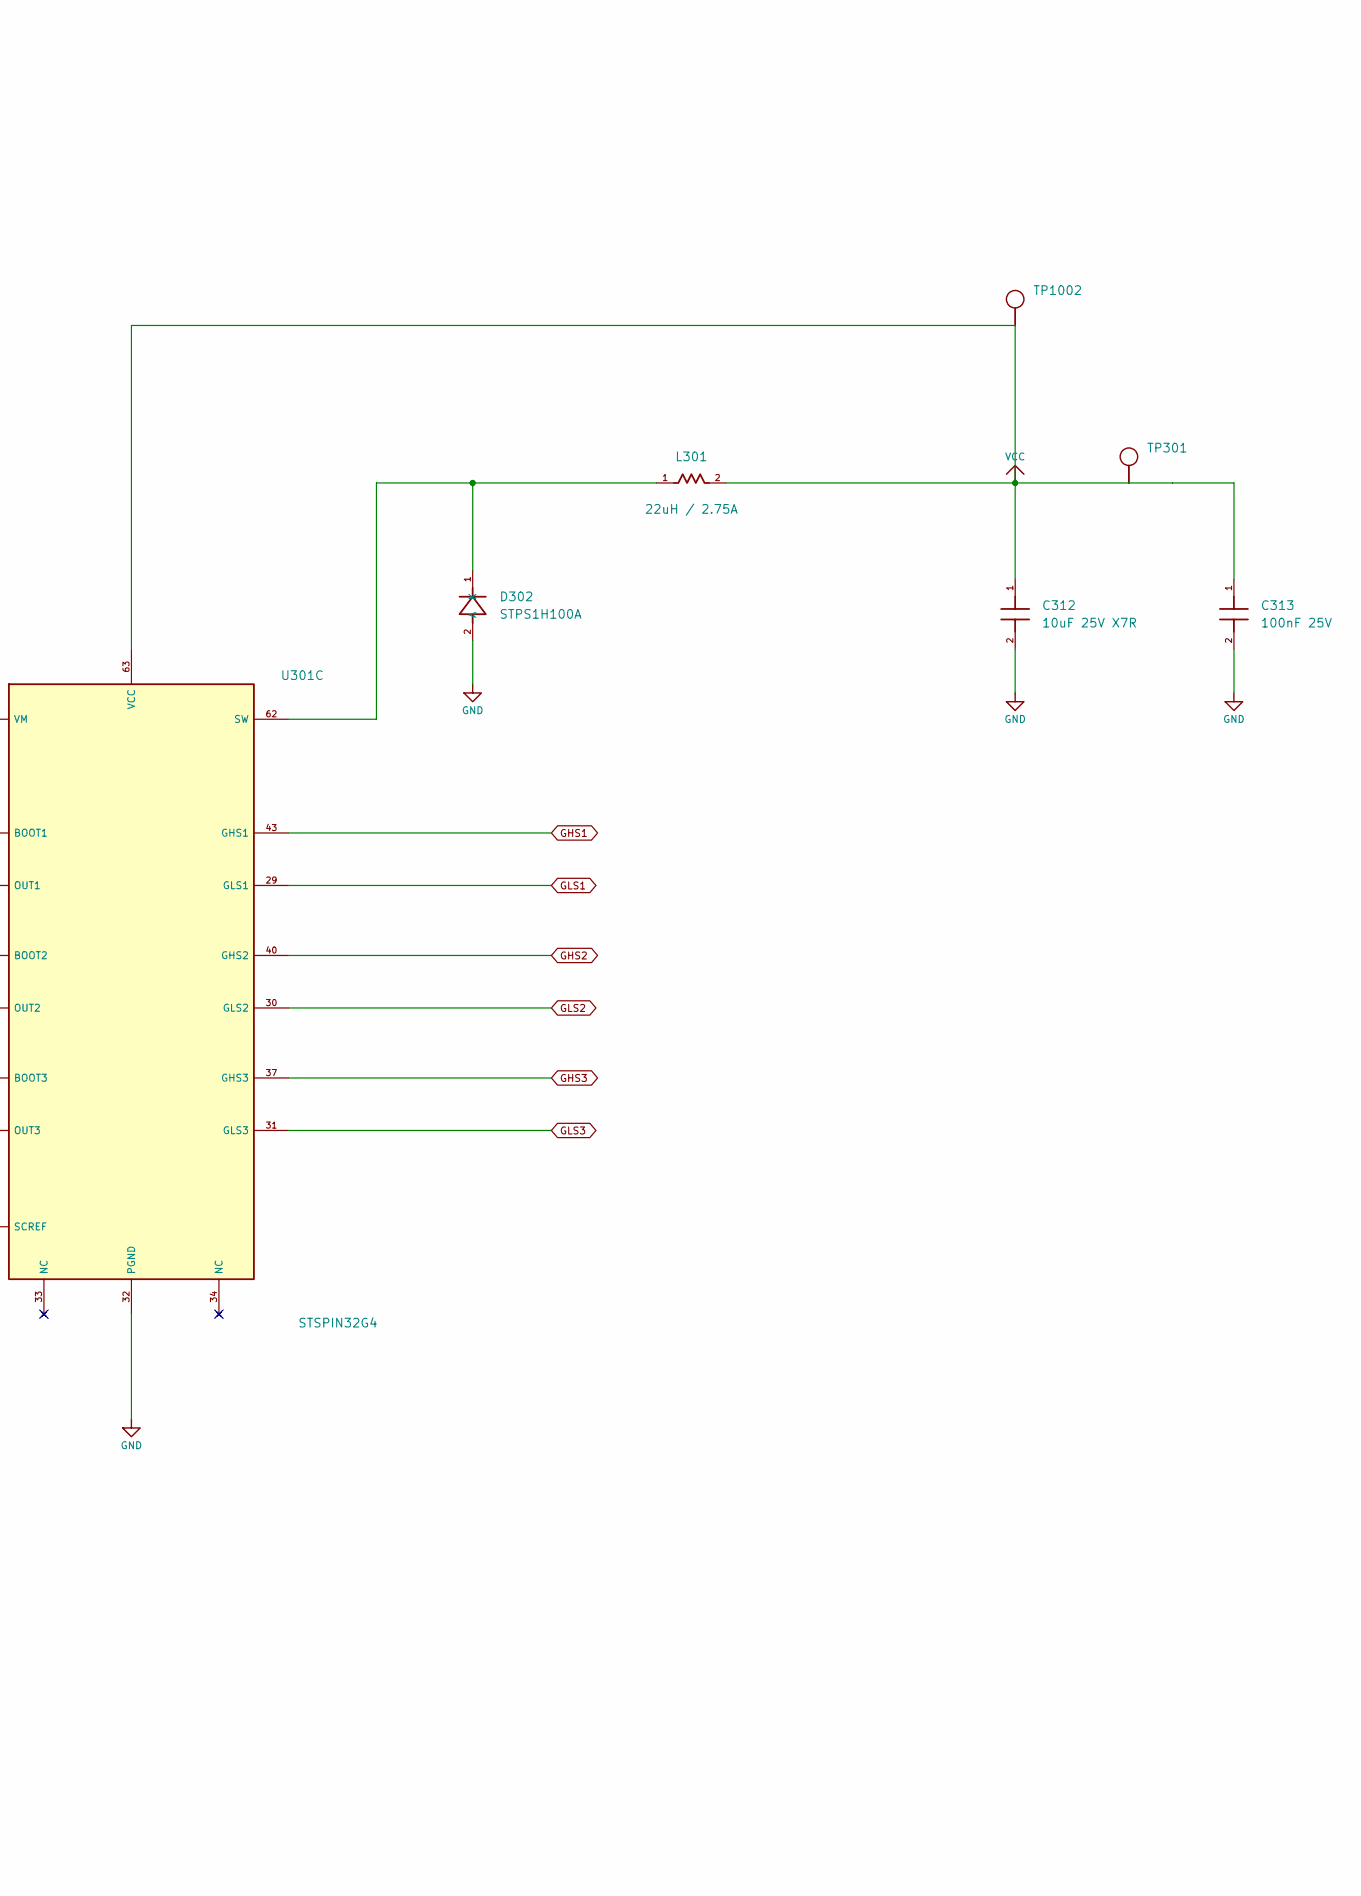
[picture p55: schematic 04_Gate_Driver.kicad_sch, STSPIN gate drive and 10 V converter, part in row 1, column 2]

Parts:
C311: 220nF 100V; C_0805_2012Metric; Rating See Value; generic low-voltage passives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
C312: 10uF 25V X7R; C_1210_3225Metric; Rating See Value; generic low-voltage passives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
C313: 100nF 25V; C_0603_1608Metric; Rating See Value; generic low-voltage passives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
C314: 10nF; C_0603_1608Metric; Rating See Value; generic low-voltage passives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
D302: STPS1H100A; D_SMA; Rating See Value; generic low-voltage passives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; MPN STPS1H100A
L301: 22uH / 2.75A; WE_LHMI_7050_74437349220; Rating See Value; generic low-voltage passives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; MPN 74437349220
R310: 100k; R_0603_1608Metric; Rating See Value; generic low-voltage passives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
R311: 10k; R_0603_1608Metric; Rating See Value; generic low-voltage passives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
R312: 1k; R_0603_1608Metric; Rating See Value; generic low-voltage passives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
TP301: VCC; TestPoint_Pad_D1.5mm; Rating See Value; generic low-voltage passives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; MPN PCB feature
TP302: SCREF; TestPoint_Pad_D1.5mm; Rating See Value; generic low-voltage passives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; MPN PCB feature
TP1002: VCC; TestPoint_Pad_D1.0mm; Rating See Value; generic low-voltage passives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; MPN PCB feature
U301: STSPIN32G4; QFN-64-1EP_9x9mm_P0.5mm_EP4.1x4.1mm_ThermalVias; Rating See Value; generic low-voltage passives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; MPN STSPIN32G4

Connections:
3V3: R310.1; also elsewhere on the board
BOOT1: U301.41 (BOOT1); also elsewhere on the board
BOOT2: U301.38 (BOOT2); also elsewhere on the board
BOOT3: U301.35 (BOOT3); also elsewhere on the board
GHS1: U301.43 (GHS1); also elsewhere on the board
GHS2: U301.40 (GHS2); also elsewhere on the board
GHS3: U301.37 (GHS3); also elsewhere on the board
GLS1: U301.29 (GLS1); also elsewhere on the board
GLS2: U301.30 (GLS2); also elsewhere on the board
GLS3: U301.31 (GLS3); also elsewhere on the board
GND: C311.2, C312.2, C313.2, C314.2, D302.2 (A), R311.2, U301.32 (PGND); also elsewhere on the board
unnamed: D302.1 (K), L301.1, U301.62 (SW)
unnamed: R310.2, R311.1, R312.1
unnamed: C314.1, R312.2, TP302.1, U301.52 (SCREF)
OUT1: U301.42 (OUT1); also elsewhere on the board
OUT2: U301.39 (OUT2); also elsewhere on the board
OUT3: U301.36 (OUT3); also elsewhere on the board
VCC: C312.1, C313.1, L301.2, TP301.1, TP1002.1, U301.63 (VCC); also elsewhere on the board
VM: C311.1, U301.61 (VM); also elsewhere on the board

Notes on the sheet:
GATE DRIVER / VCC CONVERTER
VDS FAULT REFERENCE
SCREF is a VDS fault threshold (~0.30 V), not a precision phase-current limit. Configure COMP1/2/4 and TIM1 break before enabling PWM.
VCC starts at 8 V. Reapply the 10 V setting after each VM return. REGIN and REG3V3/VDD use external 3V3 (unit B). Gate supply stays off with USB alone.

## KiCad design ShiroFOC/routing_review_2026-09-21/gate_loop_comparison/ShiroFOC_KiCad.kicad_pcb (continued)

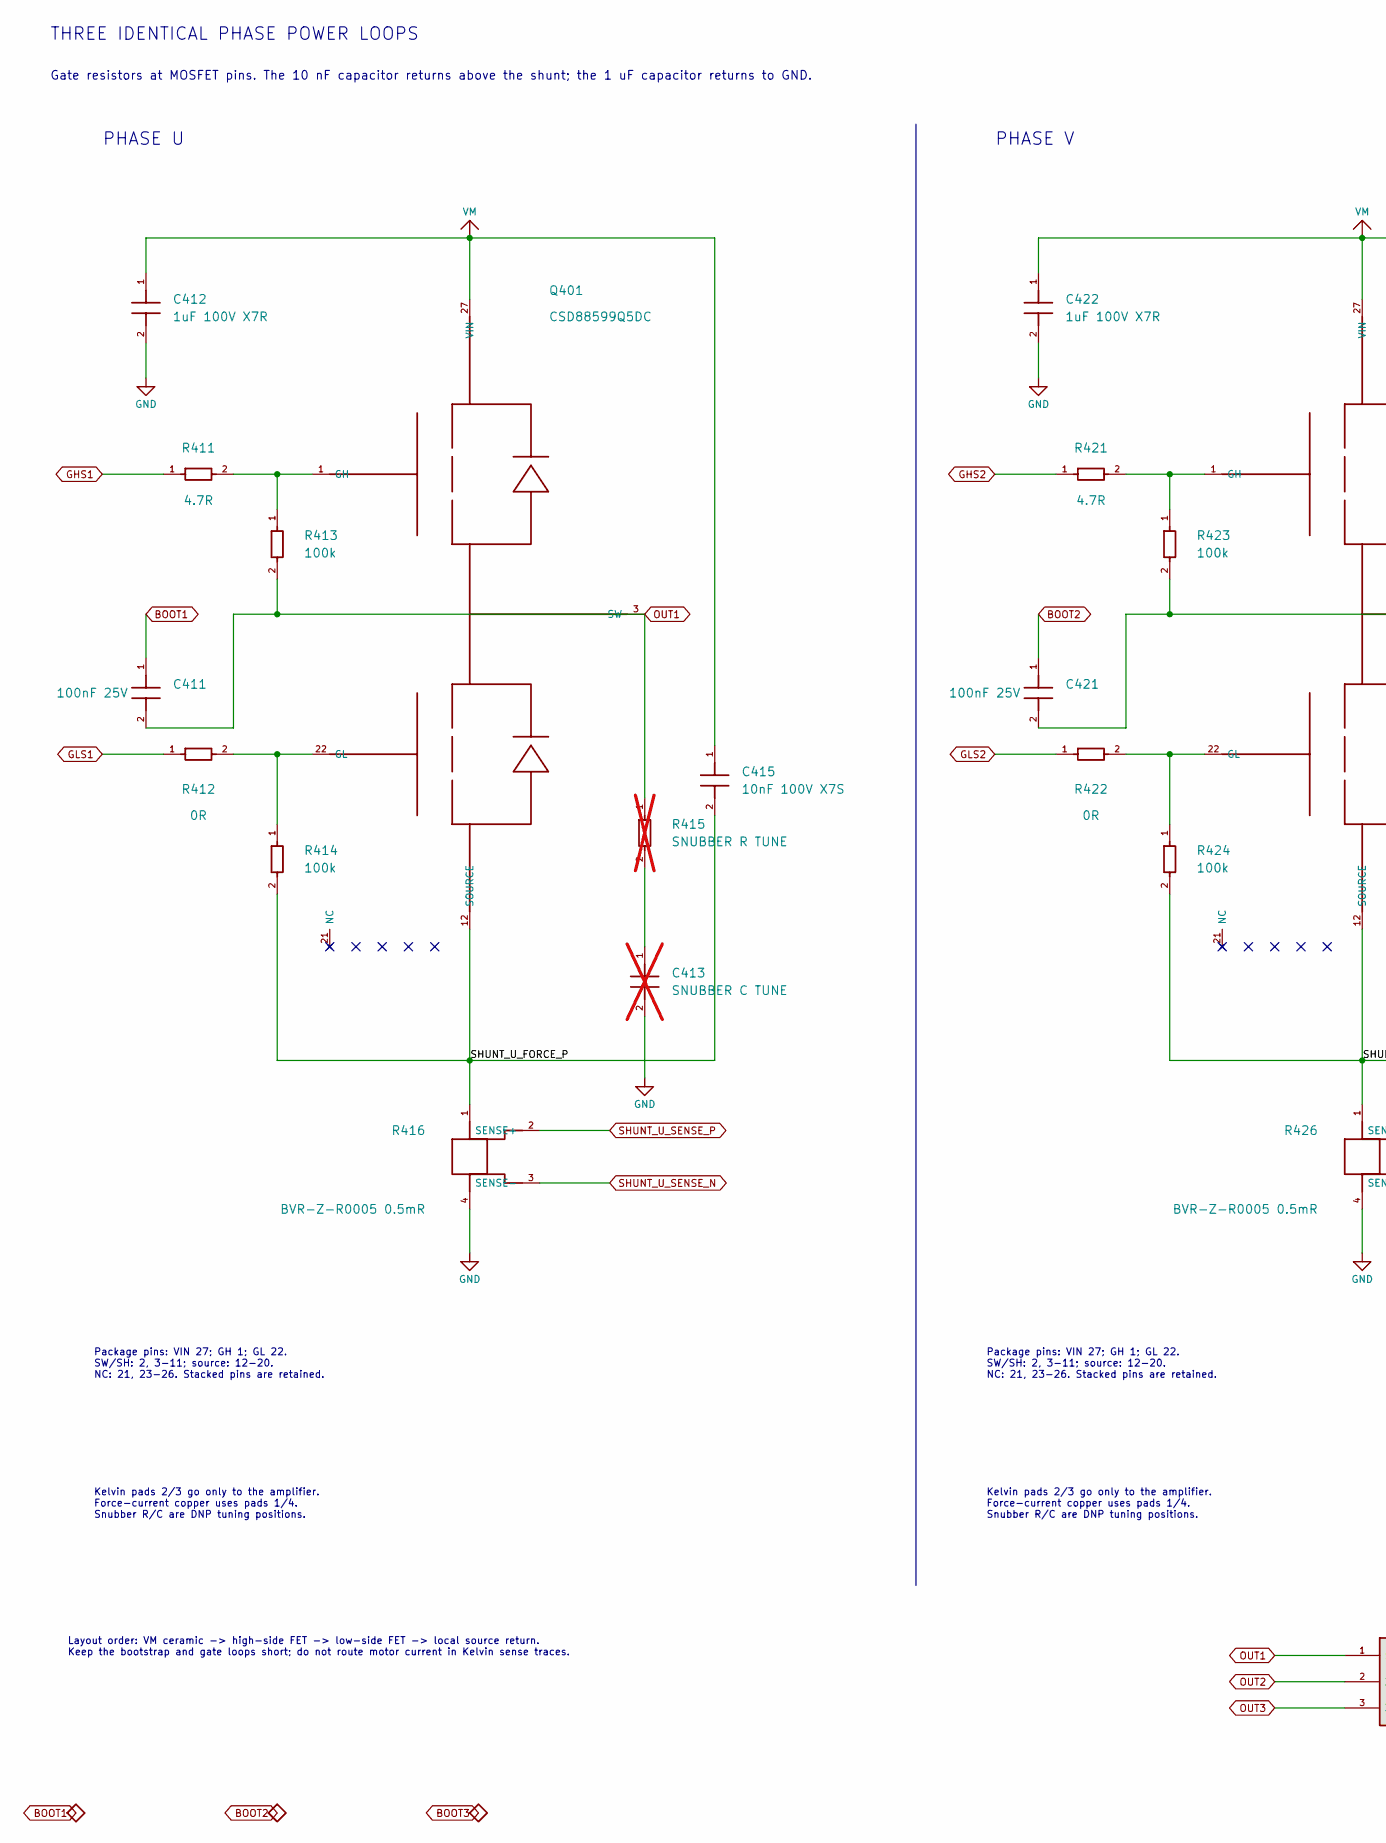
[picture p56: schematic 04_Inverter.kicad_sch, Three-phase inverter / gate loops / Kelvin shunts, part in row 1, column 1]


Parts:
C411, C421, C431: 100nF 25V; C_0603_1608Metric; Rating See Value; generic low-voltage passives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
C412, C422, C432: 1uF 100V X7R; C_1210_3225Metric; Rating See Value; generic low-voltage passives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
C413, C423, C433: SNUBBER C TUNE; C_1210_3225Metric; Rating See Value; generic low-voltage passives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; not fitted
C415, C425, C435: 10nF 100V X7S; C_0402_1005Metric; Rating See Value; generic low-voltage passives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
J401: MOTOR U/V/W; SolderWire-6sqmm_1x03_P14mm_D3.5mm_OD7mm; Rating See Value; generic low-voltage passives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
Q401, Q402, Q403: CSD88599Q5DC; CSD88599Q5DC_DMM0022A; Rating See Value; generic low-voltage passives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; MPN CSD88599Q5DC
R411, R421, R431: 4.7R; R_0603_1608Metric; Rating See Value; generic low-voltage passives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
R412, R422, R432: 0R; R_0603_1608Metric; Rating See Value; generic low-voltage passives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
R413, R414, R423, R424, R433, R434: 100k; R_0603_1608Metric; Rating See Value; generic low-voltage passives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
R415, R425, R435: SNUBBER R TUNE; R_2512_6332Metric; Rating See Value; generic low-voltage passives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; not fitted
R416, R426, R436: BVR-Z-R0005 0.5mR; R_Shunt_Isabellenhuette_BVR4026; Rating See Value; generic low-voltage passives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; MPN BVR-Z-R0005-1.0

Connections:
/Three-phase bridge/SHUNT_U_FORCE_P: C415.2, Q401.12 (SOURCE), Q401.13 (SOURCE), Q401.14 (SOURCE), Q401.15 (SOURCE), Q401.16 (SOURCE), Q401.17 (SOURCE), Q401.18 (SOURCE), Q401.19 (SOURCE), Q401.20 (SOURCE), R414.2, R416.1
/Three-phase bridge/SHUNT_V_FORCE_P: C425.2, Q402.12 (SOURCE), Q402.13 (SOURCE), Q402.14 (SOURCE), Q402.15 (SOURCE), Q402.16 (SOURCE), Q402.17 (SOURCE), Q402.18 (SOURCE), Q402.19 (SOURCE), Q402.20 (SOURCE), R424.2, R426.1
/Three-phase bridge/SHUNT_W_FORCE_P: C435.2, Q403.12 (SOURCE), Q403.13 (SOURCE), Q403.14 (SOURCE), Q403.15 (SOURCE), Q403.16 (SOURCE), Q403.17 (SOURCE), Q403.18 (SOURCE), Q403.19 (SOURCE), Q403.20 (SOURCE), R434.2, R436.1
BOOT1: C411.1; also elsewhere on the board
BOOT2: C421.1; also elsewhere on the board
BOOT3: C431.1; also elsewhere on the board
GHS1: R411.1; also elsewhere on the board
GHS2: R421.1; also elsewhere on the board
GHS3: R431.1; also elsewhere on the board
GLS1: R412.1; also elsewhere on the board
GLS2: R422.1; also elsewhere on the board
GLS3: R432.1; also elsewhere on the board
GND: C412.2, C413.2, C422.2, C423.2, C432.2, C433.2, R416.4, R426.4, R436.4; also elsewhere on the board
unnamed: C413.1, R415.2
unnamed: C423.1, R425.2
unnamed: C433.1, R435.2
unnamed: Q401.1 (GH), R411.2, R413.1
unnamed: Q401.22 (GL), R412.2, R414.1
unnamed: Q402.1 (GH), R421.2, R423.1
unnamed: Q402.22 (GL), R422.2, R424.1
unnamed: Q403.1 (GH), R431.2, R433.1
unnamed: Q403.22 (GL), R432.2, R434.1
OUT1: C411.2, J401.1, Q401.2 (SH), Q401.3 (SW), Q401.4 (SW), Q401.5 (SW), Q401.6 (SW), Q401.7 (SW), Q401.8 (SW), Q401.9 (SW), Q401.10 (SW), Q401.11 (SW), R413.2, R415.1; also elsewhere on the board
OUT2: C421.2, J401.2, Q402.2 (SH), Q402.3 (SW), Q402.4 (SW), Q402.5 (SW), Q402.6 (SW), Q402.7 (SW), Q402.8 (SW), Q402.9 (SW), Q402.10 (SW), Q402.11 (SW), R423.2, R425.1; also elsewhere on the board
OUT3: C431.2, J401.3, Q403.2 (SH), Q403.3 (SW), Q403.4 (SW), Q403.5 (SW), Q403.6 (SW), Q403.7 (SW), Q403.8 (SW), Q403.9 (SW), Q403.10 (SW), Q403.11 (SW), R433.2, R435.1; also elsewhere on the board
SHUNT_U_SENSE_N: R416.3 (SENSE-); also elsewhere on the board
SHUNT_U_SENSE_P: R416.2 (SENSE+); also elsewhere on the board
SHUNT_V_SENSE_N: R426.3 (SENSE-); also elsewhere on the board
SHUNT_V_SENSE_P: R426.2 (SENSE+); also elsewhere on the board
SHUNT_W_SENSE_N: R436.3 (SENSE-); also elsewhere on the board
SHUNT_W_SENSE_P: R436.2 (SENSE+); also elsewhere on the board
VM: C412.1, C415.1, C422.1, C425.1, C432.1, C435.1, Q401.27 (VIN), Q402.27 (VIN), Q403.27 (VIN); also elsewhere on the board

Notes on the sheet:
THREE IDENTICAL PHASE POWER LOOPS
Gate resistors at MOSFET pins. The 10 nF capacitor returns above the shunt; the 1 uF capacitor returns to GND.
PHASE U
Package pins: VIN 27; GH 1; GL 22. SW/SH: 2, 3-11; source: 12-20. NC: 21, 23-26. Stacked pins are retained.
Kelvin pads 2/3 go only to the amplifier. Force-current copper uses pads 1/4. Snubber R/C are DNP tuning positions.
PHASE V
PHASE W
Layout order: VM ceramic -> high-side FET -> low-side FET -> local source return. Keep the bootstrap and gate loops short; do not route motor current in Kelvin sense traces.



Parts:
C414, C424, C434: 47pF C0G; C_0603_1608Metric; Rating See Value; generic low-voltage passives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; not fitted
C711, C712, C713: 10nF; C_0603_1608Metric; Rating See Value; generic low-voltage passives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
R410, R420, R430, R441, R442, R443: 56k 0.1%; R_0603_1608Metric; Rating See Value; generic low-voltage passives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
R417, R418, R427, R428, R437, R438: 1k 0.1%; R_0603_1608Metric; Rating See Value; generic low-voltage passives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
R419, R429, R439: 28k 0.1%; R_0603_1608Metric; Rating See Value; generic low-voltage passives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
R701, R702, R703: 4.7k 1%; R_0603_1608Metric; Rating See Value; generic low-voltage passives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
R711, R712, R713: 1k; R_0603_1608Metric; Rating See Value; generic low-voltage passives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
TH701, TH702, TH703: 10k NTC B3380; R_0603_1608Metric; Rating See Value; generic low-voltage passives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; MPN NCP18XH103F03RB
TP701: NTC_A; TestPoint_Pad_D1.0mm; Rating See Value; generic low-voltage passives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; MPN PCB feature
TP702: NTC_B; TestPoint_Pad_D1.0mm; Rating See Value; generic low-voltage passives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; MPN PCB feature
TP703: NTC_C; TestPoint_Pad_D1.0mm; Rating See Value; generic low-voltage passives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; MPN PCB feature
TP1018: OPO_U1; TestPoint_Pad_D1.0mm; Rating See Value; generic low-voltage passives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; MPN PCB feature
TP1019: OPO_V1; TestPoint_Pad_D1.0mm; Rating See Value; generic low-voltage passives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; MPN PCB feature
TP1020: OPO_W1; TestPoint_Pad_D1.0mm; Rating See Value; generic low-voltage passives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; MPN PCB feature
U301: STSPIN32G4; QFN-64-1EP_9x9mm_P0.5mm_EP4.1x4.1mm_ThermalVias; Rating See Value; generic low-voltage passives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; MPN STSPIN32G4

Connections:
3V3: R701.1, R702.1, R703.1; also elsewhere on the board
/Current / temperature/NTC_A_RAW: R701.2, R711.1, TH701.1
/Current / temperature/NTC_B_RAW: R702.2, R712.1, TH702.1
/Current / temperature/NTC_C_RAW: R703.2, R713.1, TH703.1
/Current / temperature/OPN_U1: C414.2, R418.2, R419.2, U301.16 (-)
/Current / temperature/OPN_V1: C424.2, R428.2, R429.2, U301.22 (-)
/Current / temperature/OPN_W1: C434.2, R438.2, R439.2, U301.25 (-)
/Current / temperature/OPP_U1: R410.2, R417.2, R441.1, U301.14 (+)
/Current / temperature/OPP_V1: R420.2, R427.2, R442.1, U301.20 (+)
/Current / temperature/OPP_W1: R430.2, R437.2, R443.1, U301.23 (+)
GND: C711.2, C712.2, C713.2, R441.2, R442.2, R443.2, TH701.2, TH702.2, TH703.2; also elsewhere on the board
NTC_PHASE_A: C711.1, R711.2, TP701.1; also elsewhere on the board
NTC_PHASE_B: C712.1, R712.2, TP702.1; also elsewhere on the board
NTC_PHASE_C: C713.1, R713.2, TP703.1; also elsewhere on the board
OPO_U1: C414.1, R419.1, TP1018.1, U301.15 (OUT)
OPO_V1: C424.1, R429.1, TP1019.1, U301.19 (OUT)
OPO_W1: C434.1, R439.1, TP1020.1, U301.24 (OUT)
SHUNT_U_SENSE_N: R418.1; also elsewhere on the board
SHUNT_U_SENSE_P: R417.1; also elsewhere on the board
SHUNT_V_SENSE_N: R428.1; also elsewhere on the board
SHUNT_V_SENSE_P: R427.1; also elsewhere on the board
SHUNT_W_SENSE_N: R438.1; also elsewhere on the board
SHUNT_W_SENSE_P: R437.1; also elsewhere on the board
VREF+: R410.1, R420.1, R430.1; also elsewhere on the board

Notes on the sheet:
MATCHED CURRENT CHANNELS AND LOCAL MOSFET TEMPERATURE
VOUT = VREF/2 + 28 x (SENSE+ - SENSE-). At 0.5 mOhm: 14 mV/A. Bias resistors establish the bipolar zero-current point.
PHASE U / OPAMP1
COMP1 monitors the + input. Configure DAC3 threshold and TIM1 break before any gate PWM is enabled.
NTC A - place beside phase U
PHASE V / OPAMP2
COMP2 monitors the + input. Configure DAC3 threshold and TIM1 break before any gate PWM is enabled.
NTC B - place beside phase V
PHASE W / OPAMP3
COMP4 monitors the + input. Configure DAC3 threshold and TIM1 break before any gate PWM is enabled.
NTC C - place beside phase W
NTC faults: open -> ADC near 3V3; short -> ADC near GND. Use the hottest valid channel and calibrate protection against measured temperature.



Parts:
C501: 1uF 25V; C_0603_1608Metric; Rating See Value; generic low-voltage passives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
C502: 100nF 25V; C_0603_1608Metric; Rating See Value; generic low-voltage passives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
C503: 100nF; C_0603_1608Metric; Rating See Value; generic low-voltage passives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
C504: 1nF C0G; C_0603_1608Metric; Rating See Value; generic low-voltage passives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
D501: BZT52C12 12V; D_SOD-123; Rating See Value; generic low-voltage passives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; MPN BZT52C12
D502, D503: BAT54H; D_SOD-123F; Rating See Value; generic low-voltage passives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; MPN BAT54H,115
D504: B5100C 100V 5A; D_SMC; Rating See Value; generic low-voltage passives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; MPN B5100C-13-F
J501: BRAKE RESISTOR; SolderWire-2sqmm_1x02_P7.8mm_D2mm_OD3.9mm; Rating See Value; generic low-voltage passives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
Q501: CSD19531Q5A 100V; CSD19531Q5A_Q5A_DQJ0008A; Rating See Value; generic low-voltage passives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; MPN CSD19531Q5A
R501, R504, R505: 10k; R_0603_1608Metric; Rating See Value; generic low-voltage passives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
R502: 33R; R_0603_1608Metric; Rating See Value; generic low-voltage passives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
R503: 4.7R; R_0603_1608Metric; Rating See Value; generic low-voltage passives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
R506, R507, R508: 150k 0.1% 100V; R_1206_3216Metric; Rating See Value; generic low-voltage passives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
R509: 12.7k 0.1%; R_0603_1608Metric; Rating See Value; generic low-voltage passives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
R510: 1M 0.1%; R_0603_1608Metric; Rating See Value; generic low-voltage passives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
TP501: BRAKE_GATE; TestPoint_Pad_D1.5mm; Rating See Value; generic low-voltage passives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; MPN PCB feature
TP502: BRK_SW; TestPoint_Pad_D1.5mm; Rating See Value; generic low-voltage passives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; MPN PCB feature
U501: UCC27517ADBVR; SOT-23-5; Rating See Value; generic low-voltage passives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; MPN UCC27517ADBVR
U502: TLV3012BIDBVR; SOT-23-6; Rating See Value; generic low-voltage passives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; MPN TLV3012BIDBVR

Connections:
3V3: C503.1, U502.6 (VDD); also elsewhere on the board
/Brake chopper/BRAKE_OV_CMD: D503.2 (A), R510.1, U502.1 (OUT)
/Brake chopper/BRAKE_PWM_DRV: D502.1 (K), D503.1 (K), R505.1, U501.3 (IN+)
BRAKE_PWM: R501.1, R502.1; also elsewhere on the board
GND: C501.2, C502.2, C503.2, C504.2, D501.2 (A), Q501.1 (S), Q501.2 (S), Q501.3 (S), R501.2, R504.2, R505.2, R509.2, U501.2 (GND), U501.4 (IN-), U502.2 (GND); also elsewhere on the board
unnamed: D501.1 (K), Q501.4 (G), R503.2, R504.1, TP501.1
unnamed: D502.2 (A), R502.2
unnamed: D504.2 (A), J501.2, Q501.5 (D), Q501.6 (D), Q501.7 (D), Q501.8 (D), TP502.1
unnamed: R506.2, R507.1
unnamed: R507.2, R508.1
unnamed: R503.1, U501.5 (OUT)
unnamed: C504.1, R508.2, R509.1, R510.2, U502.3 (IN+)
unnamed: U502.4 (IN-), U502.5 (REF)
VCC: C501.1, C502.1, U501.1 (VDD); also elsewhere on the board
VM: D504.1 (K), J501.1, R506.1; also elsewhere on the board

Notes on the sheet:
BRAKE CHOPPER - TWO COMMAND SOURCES, ONE GATE DRIVE
FIRMWARE / HARDWARE DIODE OR
LOCAL GATE DRIVE / POWER SWITCH
EXTERNAL DUMP R
Short / twisted resistor leads.
D504 catches lead inductance.
Q501: D = pads 5-8; S = pads 1-3; G = pad 4.
INDEPENDENT OVERVOLTAGE COMMAND
The positive-feedback resistor is wired back to IN+.
Internal 1.242 V reference returns directly to IN−.
U502 commands braking at approximately 45.9 V rising / 44.2 V falling; MCU PWM can also command the diode OR.
Fit and rate the external resistor before regeneration. Both resistor wires carry bus voltage; pulse energy is application-specific.
Place U501 decoupling / R503 / D501 at Q501. Return the driver ground to Q501 source with a short Kelvin connection.

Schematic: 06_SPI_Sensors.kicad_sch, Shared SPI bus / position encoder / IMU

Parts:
C601, C701, C702: 100nF; C_0603_1608Metric; Rating See Value; generic low-voltage passives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
C602: 1uF; C_0603_1608Metric; Rating See Value; generic low-voltage passives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
R308, R309: 10k; R_0603_1608Metric; Rating See Value; generic low-voltage passives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
R313, R314: 22R; R_0603_1608Metric; Rating See Value; generic low-voltage passives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
R601, R602, R603, R611, R714: 33R; R_0603_1608Metric; Rating See Value; generic low-voltage passives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
TP1010: SPI3_SCK; TestPoint_Pad_D1.0mm; Rating See Value; generic low-voltage passives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; MPN PCB feature
TP1011: SPI3_MISO; TestPoint_Pad_D1.0mm; Rating See Value; generic low-voltage passives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; MPN PCB feature
TP1012: SPI3_MOSI; TestPoint_Pad_D1.0mm; Rating See Value; generic low-voltage passives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; MPN PCB feature
U601: AS5047P-ATSM; TSSOP-14_4.4x5mm_P0.65mm; Rating See Value; generic low-voltage passives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; MPN AS5047P-ATSM
U701: BMI323; Bosch_LGA-14_3x2.5mm_P0.5mm; Rating See Value; generic low-voltage passives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; MPN BMI323

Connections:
3V3: C601.1, C602.1, C701.1, C702.1, R308.1, R309.1, U601.11 (VDD), U601.12 (VDD3V3), U701.5 (VDDIO), U701.8 (VDD); also elsewhere on the board
/SPI sensors/AS5047_MISO_RAW: R611.1, U601.3 (MISO)
/SPI sensors/BMI323_MISO_RAW: R714.1, U701.1 (SDO)
/SPI sensors/ENC_ON_A: R601.1, U601.7 (A)
/SPI sensors/ENC_ON_B: R602.1, U601.6 (B)
/SPI sensors/ENC_ON_I: R603.1, U601.14 (I/PWM)
/SPI sensors/SPI3_MOSI: R314.2, TP1012.1, U601.4 (MOSI), U701.14 (SDI)
/SPI sensors/SPI3_SCK: R313.2, TP1010.1, U601.2 (CLK), U701.13 (SCK)
AS5047P_CS_N: R309.2, U601.1 (CSn); also elsewhere on the board
GND: C601.2, C602.2, C701.2, C702.2, U601.5 (TEST), U601.13 (GND), U701.6 (GNDIO), U701.7 (GND); also elsewhere on the board
IMU_CS_N: R308.2, U701.12 (CSB); also elsewhere on the board
IMU_INT1: U701.4 (INT1); also elsewhere on the board
IMU_INT2: U701.9 (INT2); also elsewhere on the board
MUX_ON_A: R601.2; also elsewhere on the board
MUX_ON_B: R602.2; also elsewhere on the board
MUX_ON_I: R603.2; also elsewhere on the board
SPI3_MISO: R611.2, R714.2, TP1011.1; also elsewhere on the board
SPI3_MOSI_MCU: R314.1; also elsewhere on the board
SPI3_SCK_MCU: R313.1; also elsewhere on the board

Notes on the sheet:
SPI3: one shared bus, separate chip selects, local return damping
ONBOARD POSITION ABI outputs feed the selector sheet. TEST is tied low for normal operation. Align the sensor with the shaft magnet.
IMU Mark X/Y axes on the PCB. Keep power-stage heat and switching loops away from the sensor.
Place R313/R314 at the MCU. Place R611/R714 at their sensor MISO pins. Chip-select pull-ups keep both peripherals deselected during reset. SPI wire crossings without a junction dot are separate nets.

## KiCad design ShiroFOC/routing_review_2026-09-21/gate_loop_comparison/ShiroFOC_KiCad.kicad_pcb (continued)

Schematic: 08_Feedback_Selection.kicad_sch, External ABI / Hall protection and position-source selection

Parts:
C603: 100nF; C_0603_1608Metric; Rating See Value; generic low-voltage passives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
C604: 100nF 50V; C_0603_1608Metric; Rating See Value; generic low-voltage passives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
D601: TPD3E001DRLR 3-line ESD; Texas_R-PDSO-N5_DRL-5; Rating See Value; generic low-voltage passives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; MPN TPD3E001DRLR
J601: EXT ENCODER / HALL; JST_GH_BM06B-GHS-TBT_1x06-1MP_P1.25mm_Vertical; Rating See Value; generic low-voltage passives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; MPN BM06B-GHS-TBT
R305, R306, R307: 10k; R_0603_1608Metric; Rating See Value; generic low-voltage passives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
R604: 0R; external load <=25mA; R_0603_1608Metric; Rating See Value; generic low-voltage passives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
R605, R606, R607: 100R; R_0603_1608Metric; Rating See Value; generic low-voltage passives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
R608, R609, R610: 10k DNP Hall pull-up; R_0603_1608Metric; Rating See Value; generic low-voltage passives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; not fitted
TP1015: FEEDBACK_A_H1; TestPoint_Pad_D1.0mm; Rating See Value; generic low-voltage passives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; MPN PCB feature
TP1016: FEEDBACK_B_H2; TestPoint_Pad_D1.0mm; Rating See Value; generic low-voltage passives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; MPN PCB feature
U602: TMUX1574PW; TSSOP-16_4.4x5mm_P0.65mm; Rating See Value; generic low-voltage passives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; MPN TMUX1574PW

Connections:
3V3: C603.1, R305.1, R604.1, R608.1, R609.1, R610.1, U602.16 (VDD); also elsewhere on the board
/Feedback selection/3V3_EXT_FB: J601.1, R604.2
/Feedback selection/FB_ESD_RAIL: C604.1, D601.5 (VCC)
/Feedback selection/MUX_EXT_A: R605.2, R608.2, U602.3 (S1B)
/Feedback selection/MUX_EXT_B: R606.2, R609.2, U602.6 (S2B)
/Feedback selection/MUX_EXT_I: R607.2, R610.2, U602.10 (S3B)
FEEDBACK_A_H1: TP1015.1, U602.4 (D1); also elsewhere on the board
FEEDBACK_B_H2: TP1016.1, U602.7 (D2); also elsewhere on the board
FEEDBACK_ENABLE_N: R305.2, U602.15 (EN_N); also elsewhere on the board
FEEDBACK_I_H3: R307.1, U602.9 (D3); also elsewhere on the board
FEEDBACK_SELECT: R306.1, U602.1 (SEL); also elsewhere on the board
GND: C603.2, C604.2, D601.3 (GND), J601.2, R306.2, R307.2, U602.8 (GND); also elsewhere on the board
MUX_ON_A: U602.2 (S1A); also elsewhere on the board
MUX_ON_B: U602.5 (S2A); also elsewhere on the board
MUX_ON_I: U602.11 (S3A); also elsewhere on the board
unnamed: D601.1 (IO1), J601.3, R605.1
unnamed: D601.2 (IO2), J601.4, R606.1
unnamed: D601.4 (IO3), J601.5, R607.1
VBUS_MUX_IN: U602.13 (S4A), U602.14 (S4B); also elsewhere on the board
VBUS_SENSE: U602.12 (D4); also elsewhere on the board

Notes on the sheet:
ONBOARD OR EXTERNAL POSITION FEEDBACK -> TIM4
External signals must stay within 0-3.3 V, including when board power is off. DNP pull-ups are for open-drain Hall outputs.
ESD rail is isolated from 3V3
PB8 / BOOT0: 10k default low. No test stub.
CHANNEL 4 - BUS ADC ISOLATION
Both select positions pass VM. Enable mux; wait 2 ms before reading VM.
Reset: disabled; onboard selected. Disable PWM before disabling this mux.

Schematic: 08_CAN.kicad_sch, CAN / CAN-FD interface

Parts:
C801: 100nF; C_0603_1608Metric; Rating See Value; generic low-voltage passives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
C802: 1uF; C_0603_1608Metric; Rating See Value; generic low-voltage passives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
D801: PESD2CANFD24V-T; SOT-23; Rating See Value; generic low-voltage passives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; MPN PESD2CANFD24V-T
J801: CAN 1; JST_GH_BM04B-GHS-TBT_1x04-1MP_P1.25mm_Vertical; Rating See Value; generic low-voltage passives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; MPN BM04B-GHS-TBT
J802: CAN 2; JST_GH_BM04B-GHS-TBT_1x04-1MP_P1.25mm_Vertical; Rating See Value; generic low-voltage passives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; MPN BM04B-GHS-TBT
JP801: TERM ENABLE; SolderJumper-2_P1.3mm_Open_Pad1.0x1.5mm; Rating See Value; generic low-voltage passives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; not fitted
R801, R805: 10k; R_0603_1608Metric; Rating See Value; generic low-voltage passives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
R802: 120R 1%; R_0603_1608Metric; Rating See Value; generic low-voltage passives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; not fitted
R803: 0R CANH link; R_0603_1608Metric; Rating See Value; generic low-voltage passives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
R804: 0R CANL link; R_0603_1608Metric; Rating See Value; generic low-voltage passives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
TP1013: FDCAN1_TX; TestPoint_Pad_D1.0mm; Rating See Value; generic low-voltage passives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; MPN PCB feature
TP1014: FDCAN1_RX; TestPoint_Pad_D1.0mm; Rating See Value; generic low-voltage passives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; MPN PCB feature
TP1022: CAN_STB; TestPoint_Pad_D1.0mm; Rating See Value; generic low-voltage passives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; MPN PCB feature
U801: TCAN3413DR; SOIC-8_3.9x4.9mm_P1.27mm; Rating See Value; generic low-voltage passives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; MPN TCAN3413DR

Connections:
3V3: C801.1, C802.1, R801.1, R805.1, U801.3 (VCC), U801.5 (VIO); also elsewhere on the board
/CAN interface/CANH_BUS: D801.1 (CANH_IN), J801.3, J802.3, R802.1, R803.2
/CAN interface/CANH_INT: R803.1, U801.7 (CANH)
/CAN interface/CANL_BUS: D801.2 (CANL_IN), J801.2, J802.2, JP801.2, R804.2
/CAN interface/CANL_INT: R804.1, U801.6 (CANL)
/CAN interface/CAN_SHIELD: J801.4, J802.4
/CAN interface/CAN_TERM_MID: JP801.1, R802.2
CAN_STB: R801.2, TP1022.1, U801.8 (STB); also elsewhere on the board
FDCAN1_RX: TP1014.1, U801.4 (RXD); also elsewhere on the board
FDCAN1_TX: R805.2, TP1013.1, U801.1 (TXD); also elsewhere on the board
GND: C801.2, C802.2, D801.3 (GND), J801.1, J802.1, U801.2 (GND); also elsewhere on the board

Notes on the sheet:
CAN: controller -> transceiver -> protected daisy-chain bus
End-node option: fit R802 and close JP801. Both DNP.
Reset state: STB high -> standby; TX high -> recessive. Configure FDCAN before taking STB low. Place D801 next to the connectors; route CANH/CANL together.
Both headers: 1 GND | 2 CANL | 3 CANH | 4 shield/drain. Pin 4 carries no supply.

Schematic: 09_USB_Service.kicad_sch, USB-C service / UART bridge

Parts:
C207: 4.7nF 2kV; C_1206_3216Metric; Rating See Value; generic low-voltage passives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; not fitted
C208: 1uF 10V; C_0603_1608Metric; Rating See Value; generic low-voltage passives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
C901, C903: 4.7uF 10V; C_0603_1608Metric; Rating See Value; generic low-voltage passives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
C902, C904: 100nF; C_0603_1608Metric; Rating See Value; generic low-voltage passives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
J201: USB-C service; USB_C_Receptacle_HRO_TYPE-C-31-M-12; Rating See Value; generic low-voltage passives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; MPN TYPE-C-31-M-12
R203, R204: 5.1k; R_0603_1608Metric; Rating See Value; generic low-voltage passives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
R205: 0R; R_0603_1608Metric; Rating See Value; generic low-voltage passives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
R901: 1k; R_0603_1608Metric; Rating See Value; generic low-voltage passives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
R902, R903: 100R; R_0603_1608Metric; Rating See Value; generic low-voltage passives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
R904: 22.1k 1%; R_0603_1608Metric; Rating See Value; generic low-voltage passives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
R905: 47.5k 1%; R_0603_1608Metric; Rating See Value; generic low-voltage passives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
TP202: 5V_USB; TestPoint_Pad_D1.5mm; Rating See Value; generic low-voltage passives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; MPN PCB feature
TP901: USB_UART_TX; TestPoint_Pad_D1.0mm; Rating See Value; generic low-voltage passives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; MPN PCB feature
TP902: USB_UART_RX; TestPoint_Pad_D1.0mm; Rating See Value; generic low-voltage passives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; MPN PCB feature
TP903: GND; TestPoint_Pad_D1.0mm; Rating See Value; generic low-voltage passives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; MPN PCB feature
TP1004: 5V_USB; TestPoint_Pad_D1.0mm; Rating See Value; generic low-voltage passives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; MPN PCB feature
U202: USBLC6-2SC6; SOT-23-6; Rating See Value; generic low-voltage passives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; MPN USBLC6-2SC6
U901: CP2102N-A02-GQFN20; SiliconLabs_QFN-20-1EP_3x3mm_P0.5mm_EP1.8x1.8mm_ThermalVias; Rating See Value; generic low-voltage passives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; MPN CP2102N-A02-GQFN20

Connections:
3V3: C901.1, C902.1, C903.1, C904.1, R901.1, U901.6 (VDD), U901.7 (VREGIN); also elsewhere on the board
5V_USB: C208.1, R205.2, TP202.1, TP1004.1; also elsewhere on the board
5V_USB_RAW: J201.A4 (VBUS), J201.A9 (VBUS), J201.B4 (VBUS), J201.B9 (VBUS), R205.1, R904.1, U202.5 (VBUS)
/USB service/CP2102_RST_N: R901.2, U901.9 (RST)
/USB service/CP2102_VBUS_SENSE: R904.2, R905.1, U901.8 (VBUS)
/USB service/UART_BRIDGE_RX: R903.2, U901.17 (RXD)
/USB service/UART_BRIDGE_TX: R902.1, U901.18 (TXD)
/USB service/USB_CC1: J201.A5 (CC1), R203.1
/USB service/USB_CC2: J201.B5 (CC2), R204.1
/USB service/USB_DM: U202.6 (IO1), U901.5 (D-)
/USB service/USB_DM_CONN: J201.A7 (D-), J201.B7 (D-), U202.1 (IO1)
/USB service/USB_DP: U202.4 (IO2), U901.4 (D+)
/USB service/USB_DP_CONN: J201.A6 (D+), J201.B6 (D+), U202.3 (IO2)
/USB service/USB_SHIELD: C207.1, J201.S1 (SHIELD)
GND: C207.2, C208.2, C901.2, C902.2, C903.2, C904.2, J201.A1 (GND), J201.A12 (GND), J201.B1 (GND), J201.B12 (GND), R203.2, R204.2, R905.2, TP903.1, U202.2 (GND), U901.3 (GND), U901.12 (GND), U901.21 (EP); also elsewhere on the board
USB_UART_RX: R902.2, TP902.1; also elsewhere on the board
USB_UART_TX: R903.1, TP901.1; also elsewhere on the board

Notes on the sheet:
USB service: connector, protection and bridge in one circuit
VBUS to control-power mux USB-only source must allow >=500 mA.
Shield capacitor C207 is DNP. Place USBLC6 at the connector.
VREGIN and VDD: both powered from 3V3
UART labels are named from the MCU point of view. TXD from U901 drives MCU RX. RTS/CTS are unused. BOOT0 and reset remain manual controls on the MCU sheet.
LAYOUT: route the USB pair continuously from J201 through U202 to U901; avoid stubs. C901/C902 belong at VREGIN; C903/C904 belong at VDD. Both pin groups use the same 3V3 rail.



Board: 4 copper layers, 80.0 x 80.0 mm, 264 parts (136 on the bottom side), 148 nets.

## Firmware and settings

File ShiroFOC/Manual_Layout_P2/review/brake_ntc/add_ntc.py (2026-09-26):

from pathlib import Path
import sys,copy,json,zipfile,hashlib,math
sys.path.insert(0,'/tmp/cascade_work')
from edit import *
P=Path(__file__).resolve().parents[2];OUT=P/'review/brake_ntc';S=Path('/Applications/KiCad/KiCad.app/Contents/SharedSupport/symbols')
backup=OUT/'before.zip'
assert not backup.exists(),'Already applied; do not rerun'
paths=list(P.glob('*.kicad_sch'))+[P/'ShiroFOC_Manual.kicad_pcb',P/'ShiroFOC_Manual.kicad_pro',P/'libs/Manual.kicad_sym',P.parent/'requirements/FIRMWARE_REQUIREMENTS.md']
with zipfile.ZipFile(backup,'w',zipfile.ZIP_DEFLATED) as z:
 for path in paths:z.write(path,str(path.relative_to(P.parent)))
(OUT/'before_hashes.json').write_text(json.dumps({str(x):hashlib.sha256(x.read_bytes()).hexdigest() for x in paths},indent=2))
# Change the functional-symbol pin types consistently in the project library and every embedded copy.
def pin_types(lib):
 for unit in children(lib,'symbol'):
  for pin in children(unit,'pin'):
   num=one(pin,'number')[1]
   if num=='11':pin[1]='input'
   elif num=='5':pin[1]='output'
for path in P.glob('*.kicad_sch'):
 d=read(path);changed=False
 for lib in children(one(d,'lib_symbols') or [],'symbol'):
  if lib[1]=='Manual:STSPIN32G4_Functional':pin_types(lib);changed=True
 if changed:write(path,d)
lp=P/'libs/Manual.kicad_sym';d=read(lp)
for lib in children(d,'symbol'):
 if lib[1]=='STSPIN32G4_Functional':pin_types(lib)
write(lp,d)
def wire(d,a,b):
 d.append(['wire',['pts',['xy',*map(str,a)],['xy',*map(str,b)]],['stroke',['width','0'],['type','default']],['uuid',uid()]])
def label(d,name,xy,glob=False,angle=0):
 x=['global_label' if glob else 'label',Q(name)]
 if glob:x.append(['shape','bidirectional'])
 x += [['at',*map(str,xy),str(angle)],['effects',['font',['size','1.016','1.016']],['justify','left' if angle==0 else 'right']+([] if glob else ['bottom'])],['uuid',uid()]]
 d.append(x)
def text(d,t,xy,size=1.27):d.append(['text',Q(t),['at',*map(str,xy),'0'],['effects',['font',['size',str(size),str(size)]],['justify','left','top']],['uuid',uid()]])
def junction(d,xy):d.append(['junction',['at',*map(str,xy)],['diameter','0'],['color','0','0','0','0'],['uuid',uid()]])
# Relocate the existing LED drawing into the free right-hand area; physical LED placement unchanged.
p=P/'MCUclockSWD.kicad_sch';d=read(p)
for refname in ['D301','R304','#PWR03Controller8']:shift(ref(d,refname),116.84,0)
for w in list(children(d,'wire')):
 pts=[tuple(map(float,x[1:])) for x in children(one(w,'pts'),'xy')]
 if pts==[(163.83,99.06),(175.26,99.06)]:d.remove(w)
 elif pts in [[(185.42,99.06),(201.93,99.06)],[(212.09,92.71),(212.09,99.06)]]:shift(w,116.84,0)
for l in children(d,'label'):
 if l[1]=='SPARE_GPIO_1':l[1]=Q('STATUS_LED_N')
wire(d,(283.21,99.06),(292.1,99.06));label(d,'STATUS_LED_N',(283.21,99.06))
wire(d,(163.83,99.06),(179.07,99.06));label(d,'NTC_BRAKE',(179.07,99.06),True)
text(d,'STATUS LED: PC15, active low / open drain.\nR304 limits LED sink current; keep LSE disabled.\nPC2 is now ADC12_IN8 for the external brake NTC.',(279.4,109.22),1.016)
# 2.2k bounds LED current below 1.65mA even with a shorted LED, leaving room for PC14.
update(ref(d,'R304'),'Value','2.2k');pr=prop(ref(d,'R304'),'Procurement')
if pr:pr[2]=Q('2.2k 1%, 0603; low-current active-low status LED')
write(p,d)
# New block on brake sheet.
p=P/'07_Brake_Chopper.kicad_sch';d=read(p);libstore=one(d,'lib_symbols');root=one(read(P/'ShiroFOC_Manual.kicad_sch'),'uuid')[1];sheet=one(d,'uuid')[1]
def std(lib,name):
 id=lib+':'+name
 if not any(x[1]==id for x in children(libstore,'symbol')):
  x=copy.deepcopy(next(x for x in children(read(S/(lib+'.kicad_sym')),'symbol') if x[1]==name));assert not one(x,'extends');x[1]=Q(id);libstore.append(x)
 return id
new=[]
def component(lib,name,r,v,xy,fp,angle=0,mpn='',ds=''):
 id=std(lib,name);x=['symbol',['lib_id',Q(id)],['at',*map(str,xy),str(angle)],['unit','1'],['in_bom','yes'],['on_board','yes'],['dnp','no'],['uuid',uid()]]
 for key,value,offset,hide in [('Reference',r,-5.08,False),('Value',v,-2.54,False),('Footprint',fp,0,True),('Datasheet',ds,0,True),('MPN',mpn,0,True)]:
  x.append(['property',Q(key),Q(value),['at',str(xy[0]+(5.08 if name in ['R','C'] and angle==0 else 0)),str(xy[1]+offset),'0'],['effects',['font',['size','1.016','1.016']]]+([['hide','yes']] if hide else [])])
 x.append(['instances',['project',Q('ShiroFOC_Manual'),['path',Q('/'+root+'/'+sheet),['reference',Q(r)],['unit','1']]]]);d.append(x);new.append({'ref':r,'footprint':fp,'uuid':one(x,'uuid')[1],'sheet':sheet});return x
# connector rotated 180: pin1 at x+5.08,y; pin2 at x+5.08,y-2.54
component('Connector_Generic','Conn_01x02','J502','BRAKE NTC',(218.44,212.09),'Connector_JST:JST_GH_SM02B-GHS-TB_1x02-1MP_P1.25mm_Horizontal',180,'SM02B-GHS-TB(LF)(SN)')
component('Device','R','R511','10k 1%',(241.3,198.12),'Resistor_SMD:R_0603_1608Metric')
component('Device','R','R512','4.7k 1%',(266.7,212.09),'Resistor_SMD:R_0603_1608Metric',90)
component('Device','C','C505','100nF 16V',(289.56,224.79),'Capacitor_SMD:C_0603_1608Metric')
component('Diode','BAT54S','D505','BAT54S',(320.04,212.09),'Package_TO_SOT_SMD:SOT-23',90,'BAT54S,215','https://assets.nexperia.com/documents/data-sheet/BAT54S.pdf')
# 3V3 divider -> series resistor -> filtered/clamped ADC. BAT54S rotated90:1bottom(GND),2top(3V3),3right(signal).
for a,b in [((223.52,212.09),(241.3,212.09)),((241.3,212.09),(262.89,212.09)),((241.3,201.93),(241.3,212.09)),((241.3,190.5),(241.3,194.31)),((270.51,212.09),(289.56,212.09)),((289.56,212.09),(289.56,220.98)),((289.56,228.6),(289.56,232.41)),((289.56,212.09),(297.18,212.09)),((297.18,212.09),(297.18,236.22)),((297.18,236.22),(332.74,236.22)),((332.74,236.22),(332.74,212.09)),((325.12,212.09),(332.74,212.09)),((332.74,212.09),(347.98,212.09)),((320.04,204.47),(320.04,190.5)),((320.04,219.71),(320.04,232.41)),((223.52,209.55),(228.6,209.55)),((228.6,209.55),(228.6,232.41))]:wire(d,a,b)
for xy in [(241.3,212.09),(289.56,212.09),(332.74,212.09)]:junction(d,xy)
label(d,'NTC_BRAKE',(347.98,212.09),True)
label(d,'BRAKE_NTC_RAW',(241.3,212.09))
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

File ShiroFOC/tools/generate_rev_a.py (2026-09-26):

#!/usr/bin/env python3
"""Generate the ShiroFOC Rev A KiCad schematic hierarchy.

Circuit definitions and datasheet-derived footprints. native_rev_a.py writes
the editable KiCad 9 hierarchy directly. Legacy rendering helpers are retained
for reference only and are not part of the release build.
"""

from __future__ import annotations

from dataclasses import dataclass, field
from pathlib import Path
import json
import shutil
import re


ROOT = Path(__file__).resolve().parents[1] / "ShiroFOC_KiCad"
LIBDIR = ROOT / "libs"
FPDIR = LIBDIR / "ShiroFOC.pretty"


@dataclass
class Pin:
    name: str
    number: str
    x: int
    y: int
    length: int = 300
    orient: str = "R"
    etype: str = "P"
    visible: bool = True


@dataclass
class Symbol:
    name: str
    ref: str
    width: int
    height: int
    pins: list[Pin]
    description: str = ""

    def legacy(self) -> str:
        lines = [
            f"#\n# {self.name}\n#",
            f"DEF {self.name} {self.ref} 0 40 Y Y 1 F N",
            f'F0 "{self.ref}" 0 {self.height // 2 + 180} 50 H V C CNN',
            f'F1 "{self.name}" 0 {-self.height // 2 - 180} 50 H V C CNN',
            "DRAW",
            f"S {-self.width//2} {self.height//2} {self.width//2} {-self.height//2} 0 1 12 f",
        ]
        for p in self.pins:
            vis = "" if p.visible else " N"
            lines.append(
                f"X {p.name} {p.number} {p.x} {p.y} {p.length} {p.orient} "
                f"40 35 1 1 {p.etype}{vis}"
            )
        lines += ["ENDDRAW", "ENDDEF"]
        return "\n".join(lines)

    def endpoint(self, pin_number: str, x: int, y: int) -> tuple[int, int]:
        p = next(p for p in self.pins if p.number == str(pin_number))
        return x + p.x, y - p.y


def lr_symbol(name: str, ref: str, left: list[tuple[str, str]], right: list[tuple[str, str]],
              width: int = 1600, pitch: int = 150, pin_len: int = 300) -> Symbol:
    n = max(len(left), len(right), 2)
    height = max(700, (n + 1) * pitch)
    y0_l = (len(left) - 1) * pitch // 2
    y0_r = (len(right) - 1) * pitch // 2
    pins = []
    for i, (num, pname) in enumerate(left):
        pins.append(Pin(pname, str(num), -width // 2 - pin_len, y0_l - i * pitch, pin_len, "R"))
    for i, (num, pname) in enumerate(right):
        pins.append(Pin(pname, str(num), width // 2 + pin_len, y0_r - i * pitch, pin_len, "L"))
    return Symbol(name, ref, width, height, pins)


def two_pin(name: str, ref: str) -> Symbol:
    return Symbol(name, ref, 300, 200, [
        Pin("1", "1", -350, 0, 200, "R"),
        Pin("2", "2", 350, 0, 200, "L"),
    ])


SYMS: dict[str, Symbol] = {}


def add(sym: Symbol) -> Symbol:
    SYMS[sym.name] = sym
    return sym


RES = add(two_pin("RESISTOR", "R"))
CAP = add(two_pin("CAPACITOR", "C"))
IND = add(two_pin("INDUCTOR", "L"))
DIODE = add(two_pin("DIODE", "D"))
LED = add(two_pin("LED", "D"))
XTAL4 = add(lr_symbol("CRYSTAL_4PAD", "Y",
    [("1","XIN"),("2","CASE/GND")], [("3","XOUT"),("4","CASE/GND")],
    width=900, pitch=200, pin_len=250))
SW = add(two_pin("SWITCH", "SW"))
TP = add(Symbol("TESTPOINT", "TP", 200, 200, [Pin("TP", "1", -300, 0, 200, "R")]))


def conn(n: int) -> Symbol:
    pins = []
    y0 = (n - 1) * 200 // 2
    for i in range(n):
        pins.append(Pin(str(i + 1), str(i + 1), -600, y0 - i * 200, 300, "R"))
    return add(Symbol(f"CONN_{n}", "J", 600, max(600, n * 200 + 200), pins))


for _n in (2, 3, 4, 6, 10):
    conn(_n)


# STSPIN32G4 exact package pin names.
st_names = {
    1:"REG3V3/VDD",2:"VBAT",3:"PC13",4:"PC14",5:"PC15",6:"PF0",7:"PF1",8:"PG10/NRST",
    9:"PC0",10:"PC1",11:"PC2",12:"PC3",13:"PA0",14:"PA1",15:"PA2",16:"PA3",
    17:"PA4",18:"PA5",19:"PA6",20:"PA7",21:"PC4",22:"PC5",23:"PB0",24:"PB1",
    25:"PB2",26:"VREF+",27:"VDDA",28:"PB10",29:"GLS1",30:"GLS2",31:"GLS3",32:"PGND",
    33:"NC",34:"NC",35:"BOOT3",36:"OUT3",37:"GHS3",38:"BOOT2",39:"OUT2",40:"GHS2",
    41:"BOOT1",42:"OUT1",43:"GHS1",44:"PA8",45:"PA9",46:"PA10",47:"PA11",48:"PA12",
    49:"PA13/SWDIO",50:"PA14/SWCLK",51:"PA15",52:"SCREF",53:"PD2",54:"PB3",55:"PB4",56:"PB5",
    57:"PB6",58:"PB7",59:"PB8/BOOT0",60:"PB9",61:"VM",62:"SW",63:"VCC",64:"REGIN",65:"VSS/EP",
}
st_left = [(str(i), st_names[i]) for i in range(1, 33)]
st_right = [(str(i), st_names[i]) for i in range(65, 32, -1)]
STSPIN = add(lr_symbol("STSPIN32G4", "U", st_left, st_right, width=2600, pitch=100, pin_len=350))

LMR = add(lr_symbol("LMR36510FADDA", "U",
    [(2,"VIN"),(3,"EN"),(1,"PGND"),(9,"EP")],
    [(8,"SW"),(7,"BOOT"),(6,"VCC"),(5,"FB"),(4,"PG")], width=1500, pitch=200))

TPS = add(lr_symbol("TPS2121RUXR", "U",
    [(7,"IN1"),(2,"IN2"),(6,"PR1"),(3,"CP2"),(5,"OV1"),(4,"OV2")],
    [(1,"OUT"),(8,"OUT"),(11,"SS"),(10,"ILM"),(9,"ST"),(12,"GND")], width=1700, pitch=200))

TLV = add(lr_symbol("TLV75533PDYDR", "U",
    [(1,"IN"),(3,"EN"),(2,"GND")], [(5,"OUT"),(4,"NC")], width=1300, pitch=200))

UCC = add(lr_symbol("UCC27517ADBVR", "U",
    [(3,"IN+"),(4,"IN-"),(2,"GND")], [(5,"OUT"),(1,"VDD")], width=1300, pitch=200))

OVCOMP = add(lr_symbol("TLV3012BIDBVR", "U",
    [(3,"IN+"),(4,"IN-"),(2,"GND")], [(1,"OUT"),(5,"REF"),(6,"VDD")], width=1400, pitch=200))

AS5047 = add(lr_symbol("AS5047P", "U",
    [(1,"CSn"),(2,"CLK"),(3,"MISO"),(4,"MOSI"),(5,"TEST"),(13,"GND")],
    [(7,"A"),(6,"B"),(14,"I/PWM"),(8,"W/PWM"),(9,"V"),(10,"U"),(11,"VDD"),(12,"VDD3V3")],
    width=1700, pitch=200))

BMI = add(lr_symbol("BMI323", "U",
    [(1,"SDO"),(4,"INT1"),(5,"VDDIO"),(6,"GNDIO"),(7,"GND")],
    [(14,"SDI"),(13,"SCK"),(12,"CSB"),(9,"INT2"),(8,"VDD"),(2,"NC"),(3,"NC"),(10,"NC"),(11,"NC")],
    width=1600, pitch=200))

TMUX = add(lr_symbol("TMUX1574PW", "U",
    [(2,"S1A"),(3,"S1B"),(5,"S2A"),(6,"S2B"),(11,"S3A"),(10,"S3B"),(14,"S4A"),(13,"S4B"),(1,"SEL"),(15,"EN_N")],
    [(4,"D1"),(7,"D2"),(9,"D3"),(12,"D4"),(16,"VDD"),(8,"GND")],
    width=1800, pitch=200))

TCAN = add(lr_symbol("TCAN3413DR", "U",
    [(1,"TXD"),(4,"RXD"),(8,"STB")], [(7,"CANH"),(6,"CANL"),(3,"VCC"),(5,"VIO"),(2,"GND")], width=1400, pitch=200))

CP2102 = add(lr_symbol("CP2102N-A02-GQFN20", "U",
    [(1,"GPIO.1"),(2,"GPIO.0"),(8,"VBUS"),(5,"D-"),(4,"D+"),(7,"VREGIN"),(6,"VDD"),(9,"RST")],
    [(10,"NC"),(13,"WAKEUP"),(19,"GPIO.3"),(20,"GPIO.2"),(18,"TXD"),(17,"RXD"),(16,"RTS"),(15,"CTS"),(14,"SUSPEND"),(11,"SUSPEND_N"),(3,"GND"),(12,"GND"),(21,"EP")],
    width=1800, pitch=200))

USB_ESD = add(lr_symbol("USBLC6-2SC6", "U",
    [(1,"IO1"),(3,"IO2"),(2,"GND")], [(6,"IO1"),(4,"IO2"),(5,"VBUS")], width=1200, pitch=200))

CAN_ESD = add(lr_symbol("PESD2CANFD24V", "D",
    [(1,"CANH_IN"),(2,"CANL_IN")], [(3,"GND")], width=1100, pitch=200))

TPD3E001 = add(lr_symbol("TPD3E001DRLR", "D",
    [(1,"IO1"),(2,"IO2"),(4,"IO3")], [(5,"VCC"),(3,"GND")], width=1200, pitch=200))

MOS_BRAKE = add(lr_symbol("CSD19531Q5A", "Q",
    [(4,"G")], [(5,"D"),(6,"D"),(7,"D"),(8,"D"),(1,"S"),(2,"S"),(3,"S")], width=1200, pitch=200))

SHUNT = add(Symbol("BVR_Z_R0005", "R", 700, 500, [
    Pin("FORCE+", "1", -650, 150, 300, "R"), Pin("SENSE+", "2", -650, -150, 300, "R"),
    Pin("SENSE-", "3", 650, -150, 300, "L"), Pin("FORCE-", "4", 650, 150, 300, "L"),
]))

# CSD88599Q5DC pin mapping: DMM0022A dual-cool 5 x 6 mm power block.
csd_pins = [
    Pin("GH","1",-1250,900,350,"R"), Pin("SH","2",-1250,650,350,"R"), Pin("GL","22",-1250,400,350,"R"),
]
for i, num in enumerate(range(3,12)):
    csd_pins.append(Pin("VSW",str(num),1250,900-i*100,350,"L"))
for i, num in enumerate(range(12,21)):
    csd_pins.append(Pin("PGND",str(num),1250,-250-i*100,350,"L"))
csd_pins += [Pin("VIN","27",-1250,-100,350,"R")]
for i, num in enumerate((21,23,24,25,26)):
    csd_pins.append(Pin("NC",str(num),-500+i*250,-1550,250,"U",etype="N"))
CSD88599 = add(Symbol("CSD88599Q5DC", "Q", 1800, 2600, csd_pins))

USB_C = add(lr_symbol("USB_C_16P", "J",
    [("A1","GND"),("A4","VBUS"),("A5","CC1"),("A6","D+"),("A7","D-"),("A8","SBU1"),("A9","VBUS"),("A12","GND")],
    [("B12","GND"),("B9","VBUS"),("B8","SBU2"),("B7","D-"),("B6","D+"),("B5","CC2"),("B4","VBUS"),("B1","GND"),("S1","SHIELD")],
    width=1600, pitch=200))


@dataclass
class Component:
    sym: Symbol
    ref: str
    value: str
    x: int
    y: int
    footprint: str
    datasheet: str = ""
    fields: dict[str, str] = field(default_factory=dict)


class Sheet:
    def __init__(self, filename: str, title: str, rev: str = "A"):
        self.filename = filename
        self.title = title
        self.rev = rev
        self.items: list[str] = []
        self.components: list[Component] = []
        self.uid = 0x10000000
        self.connections = {}
        self.no_connects = set()

    def comp(self, sym: Symbol, ref: str, value: str, x: int, y: int, footprint: str,
             datasheet: str = "", **fields: str) -> Component:
        c = Component(sym, ref, value, x, y, footprint, datasheet, fields)
        self.components.append(c)
        return c

    def label(self, x: int, y: int, net: str, orient: int = 0, shape: str = "BiDi"):
        self.items.append(f"Text GLabel {x} {y} {orient}    45   {shape} ~ 0\n{net}")

    def pin_label(self, c: Component, pin: str, net: str, shape: str = "BiDi"):
        self.connections[(c.ref, str(pin))] = net
        x, y = c.sym.endpoint(pin, c.x, c.y)
        p = next(p for p in c.sym.pins if p.number == str(pin))
        orient = 0 if p.orient in ("R", "U", "D") else 2
        self.label(x, y, net, orient, shape)

    def nc(self, c: Component, pin: str):
        self.no_connects.add((c.ref, str(pin)))
        x, y = c.sym.endpoint(pin, c.x, c.y)
        self.items.append(f"NoConn ~ {x} {y}")

    def wire(self, x1: int, y1: int, x2: int, y2: int):
        self.items.append(f"Wire Wire Line\n\t{x1} {y1} {x2} {y2}")

    def note(self, x: int, y: int, text: str, size: int = 60, bold: bool = False):
        b = " ~ 12" if bold else " ~ 0"
        self.items.append(f"Text Notes {x} {y} 0    {size}   {b}\n{text}")

    def render(self) -> str:
        lines = [
            "EESchema Schematic File Version 4",
            "LIBS:ShiroFOC_KiCad-cache",
            "EELAYER 29 0", "EELAYER END", "$Descr A3 16535 11693",
            "encoding utf-8", "Sheet 1 1",
            f'Title "{self.title}"', f'Date "2026-09-15"', f'Rev "{self.rev}"',
            'Comp "ShiroFOC"', 'Comment1 "Rev A first-build schematic"',
            'Comment2 "6S-10S LiPo / 18-42 V operating target"',
            'Comment3 "Prototype: validate switching, transient, and thermal behavior"',
            'Comment4 "GND and PGND are one electrical net; route returns deliberately"',
            "$EndDescr",
        ]
        for c in self.components:
            self.uid += 1
            lines += [
                "$Comp", f"L ShiroFOC_KiCad:{c.sym.name} {c.ref}", f"U 1 1 {self.uid:08X}",
                f"P {c.x} {c.y}",
                f'F 0 "{c.ref}" H {c.x} {c.y - c.sym.height//2 - 180} 50  0000 C CNN',
                f'F 1 "{c.value}" H {c.x} {c.y + c.sym.height//2 + 180} 50  0000 C CNN',
                f'F 2 "{c.footprint}" H {c.x} {c.y} 50  0001 C CNN',
                f'F 3 "{c.datasheet}" H {c.x} {c.y} 50  0001 C CNN',
            ]
            fi = 4
            for name, value in c.fields.items():
                lines.append(f'F {fi} "{value}" H {c.x} {c.y} 50  0001 C CNN "{name}"')
                fi += 1
            lines += [f"\t1    {c.x} {c.y}", "\t1 0 0 -1", "$EndComp"]
        lines += self.items
        lines.append("$EndSCHEMATC")
        return "\n".join(lines) + "\n"


def passive(sheet: Sheet, sym: Symbol, ref: str, value: str, x: int, y: int, fp: str,
            left: str, right: str, dnp: bool = False, mpn: str = "") -> Component:
    c = sheet.comp(sym, ref, value, x, y, fp, MPN=mpn, Assembly="DNP" if dnp else "FIT")
    sheet.pin_label(c, "1", left)
    sheet.pin_label(c, "2", right)
    return c


R0603 = "Resistor_SMD:R_0603_1608Metric"
C0603 = "Capacitor_SMD:C_0603_1608Metric"
C0805 = "Capacitor_SMD:C_0805_2012Metric"
C1210 = "Capacitor_SMD:C_1210_3225Metric"


def make_01() -> Sheet:
    s = Sheet("01_Battery_DC_Link.sch", "01 - Battery Input and DC Link")
    s.note(700, 500, "BATTERY INPUT / DC LINK", 90, True)
    s.note(700, 850, "Rev A: keyed XT60, no onboard reverse-polarity or precharge stage.")
    j = s.comp(SYMS["CONN_2"], "J101", "AMASS XT60PW-M", 1800, 2200,
               "Connector_AMASS:AMASS_XT60PW-M_1x02_P7.20mm_Horizontal", MPN="XT60PW-M")
    s.pin_label(j,"1","GND"); s.pin_label(j,"2","VM")
    for i, x in enumerate((3500, 4800, 6100), 1):
        passive(s,CAP,f"C10{i}","680uF 63V",x,2200,"Capacitor_SMD:CP_Elec_18x17.5","VM","GND",mpn="EEVFK1J681M")
    passive(s,CAP,"C104","4.7uF 100V X7R",7500,2200,C1210,"VM","GND")
    passive(s,CAP,"C105","100nF 100V X7R",8700,2200,C0805,"VM","GND")
    passive(s,CAP,"C106","10nF 100V C0G",9900,2200,C0603,"VM","GND")
    passive(s,RES,"R101","470k 0.25W",11100,2200,"Resistor_SMD:R_1206_3216Metric","VM","GND")
    passive(s,DIODE,"D101","VM TVS - SELECT AFTER TEST",12900,2200,"Diode_SMD:D_SMC","VM","GND",dnp=True)
    passive(s,RES,"R102","RC DAMP R - TUNE",4300,4000,"Resistor_SMD:R_2512_6332Metric","VM","VM_DAMP",dnp=True)
    passive(s,CAP,"C107","RC DAMP C - TUNE",6100,4000,"Capacitor_SMD:C_2220_5750Metric","VM_DAMP","GND",dnp=True)
    passive(s,RES,"R103","270k 0.1% 100V",7000,4000,"Resistor_SMD:R_1206_3216Metric","VM","VBUS_DIV_A")
    passive(s,RES,"R104","270k 0.1% 100V",10000,4000,"Resistor_SMD:R_1206_3216Metric","VBUS_DIV_A","VBUS_DIV")
    passive(s,RES,"R105","27k 0.1%",13200,4000,R0603,"VBUS_DIV","GND")
    passive(s,RES,"R106","1k",8200,5200,R0603,"VBUS_DIV","VBUS_MUX_IN")
    passive(s,CAP,"C108","10nF",12100,5200,C0603,"VBUS_SENSE","GND")
    for ref,net,x in (("TP101","VM",3500),("TP102","GND",5000),("TP103","VBUS_SENSE",12500)):
        t=s.comp(TP,ref,net,x,6500,"TestPoint:TestPoint_Pad_D1.5mm"); s.pin_label(t,"1",net)
    s.note(700,7600,"PLACEMENT: keep all three 680 uF capacitors close to the bridge bus. Fit local 1 uF + 10 nF / 100 V ceramics at each power block.")
    s.note(700,7950,"R102/C107 and D101 are DNP tuning positions. Select only after cable/hot-plug measurements; they are not functional requirements for first power-up.")
    s.note(700,8300,"VBUS_SENSE = VM x 27k/(540k+27k): 2.00 V at 42 V, 2.86 V at 60 V. Set the firmware overvoltage trip below the hardware transient ceiling.")
    return s


def make_02() -> Sheet:
    s=Sheet("02_Aux_Power_USB.sch","02 - Auxiliary Power, USB and Source Mux")
    s.note(600,450,"VM -> 5V_BAT; USB VBUS -> 5V_USB; USB has priority; 5V_SYS -> 3V3",80,True)
    u=s.comp(LMR,"U201","LMR36510FADDAR",3000,2600,"Package_SO:Texas_HTSOP-8-1EP_3.9x4.9mm_P1.27mm_EP2.95x4.9mm_Mask2.4x3.1mm_ThermalVias","https://www.ti.com/lit/ds/symlink/lmr36510.pdf",MPN="LMR36510FADDAR")
    for p,n in (("2","VM"),("3","VM"),("1","GND"),("9","GND"),("8","5V_SW"),("7","5V_BOOT"),("6","LMR_VCC"),("5","5V_FB")):
        s.pin_label(u,p,n)
    s.nc(u,"4")
    passive(s,CAP,"C201","2.2uF 100V X7R",1000,1750,C1210,"VM","GND")
    passive(s,CAP,"C202","220nF 100V X7R",1000,2700,C0805,"VM","GND")
    passive(s,CAP,"C203","100nF",5350,1550,C0603,"5V_BOOT","5V_SW")
    passive(s,CAP,"C204","1uF",5350,2450,C0603,"LMR_VCC","GND")
    passive(s,IND,"L201","22uH / 2.75A",5350,3350,"ShiroFOC_Footprints:WE_LHMI_7050_74437349220","5V_SW","5V_BAT",mpn="74437349220")
    passive(s,RES,"R201","100k 1%",5350,4250,R0603,"5V_BAT","5V_FB")
    passive(s,RES,"R202","24.9k 1%",5350,5050,R0603,"5V_FB","GND")
    passive(s,CAP,"C205","22uF 10V X7R",7350,3400,C1210,"5V_BAT","GND")
    passive(s,CAP,"C206","22uF 10V X7R",7350,4350,C1210,"5V_BAT","GND")

    j=s.comp(USB_C,"J201","USB-C service",3600,7450,"Connector_USB:USB_C_Receptacle_HRO_TYPE-C-31-M-12",MPN="TYPE-C-31-M-12")
    usbmap={"A1":"GND","A4":"5V_USB_RAW","A5":"USB_CC1","A6":"USB_DP_CONN","A7":"USB_DM_CONN","A9":"5V_USB_RAW","A12":"GND",
            "B12":"GND","B9":"5V_USB_RAW","B7":"USB_DM_CONN","B6":"USB_DP_CONN","B5":"USB_CC2","B4":"5V_USB_RAW","B1":"GND","S1":"USB_SHIELD"}
    for p,n in usbmap.items(): s.pin_label(j,p,n)
    s.nc(j,"A8"); s.nc(j,"B8")
    passive(s,RES,"R203","5.1k",1300,6550,R0603,"USB_CC1","GND")
    passive(s,RES,"R204","5.1k",1300,7450,R0603,"USB_CC2","GND")
    passive(s,CAP,"C207","4.7nF 2kV",1300,8350,"Capacitor_SMD:C_1206_3216Metric","USB_SHIELD","GND",dnp=True)
    esd=s.comp(USB_ESD,"U202","USBLC6-2SC6",7000,7450,"Package_TO_SOT_SMD:SOT-23-6","https://www.st.com/resource/en/datasheet/usblc6-2.pdf",MPN="USBLC6-2SC6")
    for p,n in (("1","USB_DM_CONN"),("3","USB_DP_CONN"),("2","GND"),("6","USB_DM"),("4","USB_DP"),("5","5V_USB_RAW")): s.pin_label(esd,p,n)
    passive(s,RES,"R205","0R",9000,6800,R0603,"5V_USB_RAW","5V_USB")
    passive(s,CAP,"C208","1uF 10V",9000,7700,C0603,"5V_USB","GND")

    mux=s.comp(TPS,"U203","TPS2121RUXR",10600,3550,"Package_DFN_QFN:Texas_VQFN-HR-12_2x2.5mm_P0.5mm_ThermalVias","https://www.ti.com/lit/ds/symlink/tps2121.pdf",MPN="TPS2121RUXR")
    for p,n in (("7","5V_BAT"),("2","5V_USB"),("6","MUX_PR1"),("3","MUX_CP2"),("5","MUX_OV1"),("4","MUX_OV2"),("1","5V_SYS"),("8","5V_SYS"),("11","MUX_SS"),("10","MUX_ILM"),("9","PWR_SOURCE_STATUS"),("12","GND")): s.pin_label(mux,p,n)
    passive(s,RES,"R206","15.0k 1%",7600,1200,R0603,"5V_BAT","MUX_PR1")
    passive(s,RES,"R207","5.10k 1%",7600,2250,R0603,"MUX_PR1","GND")
    passive(s,RES,"R208","10.0k 1%",9500,1200,R0603,"5V_USB","MUX_CP2")
    passive(s,RES,"R209","5.10k 1%",9500,2250,R0603,"MUX_CP2","GND")
    passive(s,RES,"R210","21.0k 1%",11400,1200,R0603,"5V_BAT","MUX_OV1")
    passive(s,RES,"R211","5.10k 1%",11400,2250,R0603,"MUX_OV1","GND")
    passive(s,RES,"R212","21.0k 1%",13300,1200,R0603,"5V_USB","MUX_OV2")
    passive(s,RES,"R213","5.10k 1%",13300,2250,R0603,"MUX_OV2","GND")
    passive(s,RES,"R214","80.6k 1%",7600,5050,R0603,"MUX_ILM","GND")
    passive(s,CAP,"C209","100nF",9500,5050,C0603,"MUX_SS","GND")
    passive(s,RES,"R215","10k",11400,5050,R0603,"3V3","PWR_SOURCE_STATUS")
    passive(s,CAP,"C210","22uF 10V X7R",13500,4050,C1210,"5V_SYS","GND")
    passive(s,CAP,"C211","100nF",13500,5050,C0603,"5V_SYS","GND")
    ldo=s.comp(TLV,"U204","TLV75533PDYDR",11600,7550,"ShiroFOC_Footprints:Texas_DYD0005A_SOT23-5","https://www.ti.com/lit/ds/symlink/tlv755p.pdf",MPN="TLV75533PDYDR")
    for p,n in (("1","5V_SYS"),("3","5V_SYS"),("2","GND"),("5","3V3")): s.pin_label(ldo,p,n)
    s.nc(ldo,"4")
    passive(s,CAP,"C212","2.2uF 10V X7R",9800,8500,C0603,"5V_SYS","GND")
    passive(s,CAP,"C213","2.2uF 10V X7R",14200,7550,C0603,"3V3","GND")
    for ref,net,x,y in (("TP201","5V_BAT",7400,5800),("TP202","5V_USB",9000,5800),("TP203","5V_SYS",13200,5800),("TP204","3V3",14200,8600)):
        t=s.comp(TP,ref,net,x,y,"TestPoint:TestPoint_Pad_D1.5mm"); s.pin_label(t,"1",net)
    s.note(700,9800,"USB priority: PR1=1.269 V and CP2=1.689 V at 5 V. ILM=80.6k sets approx. 1.5 A. OV dividers trip near 5.43 V typical.")
    s.note(700,10200,"The TLV755 has no reverse-current blocking: SWD VTREF is sense-only; never inject 3V3 from the debugger.")
    return s
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

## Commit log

2026-03-01 Initial Commit (Legacy archived)
    Now that I’ve graduated and gained more experience over the past few months, I’m narrowing the scope of ShiroDrive to make more consistent and steady progress.
2026-03-04 Stepper Mount Initial Prototype
    [StepperMountA1.stl, StepperMountA2.stl, StepperMountA3.stl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]
2026-03-04 A3 and A4 merged
    [StepperMountA1.stl, StepperMountA2.stl, StepperMountA3.stl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]
2026-03-04 minor optimizations
    [StepperMountA2.stl, StepperMountA3.stl]
2026-03-16 Day 1: 3D printed brackets
    [AxisMount1.stl, AxisMount2.stl, MotorMountA1.stl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]
2026-03-16 Day 1: revision 2
    [AxisMount1.stl]
2026-04-14 3d printed updated
    [AxisMount1.stl, AxisMount2.stl, Clamp.stl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]
2026-09-26 schematic review complete
    [01_Battery_DC_Link.kicad_sch, 01_Battery_DC_Link.sch, 01_DC_Link.kicad_sch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]
2026-09-29 Backup before 2nd encoder support
    [01_DC_Link.kicad_sch, 02_Auxiliary_Power.kicad_sch, 04_Gate_Driver.kicad_sch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]
2026-10-04 pcb layout blocks
    [01_DC_Link.kicad_sch, 02_Auxiliary_Power.kicad_sch, 04_Gate_Driver.kicad_sch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]
2026-10-04 STSPIN solder paste updated
    [01_DC_Link.kicad_sch, ShiroFOC_Manual.kicad_pcb]
2026-10-05 usb and pwr mux
    [01_DC_Link.kicad_sch, 06_Current_Temperature.kicad_sch, 07_Brake_Chopper.kicad_sch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]
2026-10-05 power section updated
    [ShiroFOC_Manual.kicad_pcb]
2026-10-07 CAN layout
    [01_DC_Link.kicad_sch, 02_Auxiliary_Power.kicad_sch, 04_Gate_Driver.kicad_sch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]
2026-10-14 can connector rewiring
2026-10-14 backup before i revise op amp resistor placement
2026-10-15 opamp circuits revised
2026-10-20 op amp traces draft
    swapped phase U and W op amps
2026-10-21 mosfet stages and opamps revamped
